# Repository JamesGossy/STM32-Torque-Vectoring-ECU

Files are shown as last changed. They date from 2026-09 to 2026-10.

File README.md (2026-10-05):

<div align="center">

# STM32 Torque Vectoring ECU

**Firmware for a four-motor torque vectoring and derating ECU on an STM32G474.**

The simulated car driving a full lap of the FSG 2024 track

*A lap of the Formula Student Germany 2024 track in the full-physics simulation this ECU
grew out of. Blue and yellow dots are cones, cyan is the racing line, the red box is the car.*

</div>

---

## What it does

The ECU sits on the car's CAN bus with four STM32 motor controllers (one per wheel,
from the STM32-Motor-Controller project). Every 10 ms it:

1. reads the driver's pedals and steering, its own IMU, and each controller's speed,
   temperature and bus voltage,
2. decides whether torque is allowed at all (startup, faults, plausibility checks),
3. works out how much torque the motors may give right now (derating),
4. splits the driver's torque request across the four wheels to help the car turn
   (torque vectoring),
5. sends each controller its current setpoint over CAN.

It can also run in **HIL mode**, where the Formula Student simulator stands in for
the car. The simulator sends steering, torque request, yaw rate and wheel speeds over
CAN, and reads back the torque the ECU commanded. The real motor controllers on the
bench take part exactly as they would on the car.

Battery management is out of scope for now: the bench runs from a lab power supply.

```mermaid
flowchart LR
    pedals["Pedals & steering"] -->|analog| ecu
    imu["IMU (LSM6DSV16X)"] -->|SPI| ecu
    ecu["Torque vectoring ECU<br/>STM32G474"]
    ecu <-->|"CAN 1 Mbit/s<br/>current setpoints / telemetry"| mc["Four motor controllers<br/>FL · FR · RL · RR"]
    sim["Formula Student sim<br/>(HIL mode)"] <-->|"CAN via CANable<br/>steering, torque request,<br/>yaw rate, wheel speeds"| ecu
    usb["PC console"] <-->|USB-C| ecu

    classDef controller fill:#eef2ff,stroke:#6366f1,color:#1e1b4b
    classDef drive fill:#ecfdf5,stroke:#059669,color:#064e3b
    classDef interface fill:#fff7ed,stroke:#ea580c,color:#7c2d12
    class ecu controller
    class mc,pedals,imu drive
    class sim,usb interface
```

## Repository layout

```
ECU_Hardware/            KiCad schematics and PCB, board requirements, sensor pinout
docs/                    pictures from the earlier full-physics simulation
ECU_Firmware/
  app/                   the application, no hardware access (runs on the board and the PC)
    app.c                100 Hz control step and the drive state machine
    torque_vectoring.c   the yaw-rate torque vectoring law
    derate.c             torque limits from temperature, speed and bus voltage
    driver_inputs.c      pedals and steering, with the Formula Student plausibility rules
    motors.c             the motor controller CAN protocol, client side
    hil.c                inputs from the HIL simulator
    imu.c, gps.c         LSM6DSV16X gyro/accel driver, NMEA reader
    console.c            USB text console
    config.h             every number: car, sensors, limits, derating thresholds
    can_protocol.h       every CAN message (shared with the simulator)
  hal/hal.h              what the app needs from a board
  hal/stm32g474/         register-level drivers: clocks, ADC+DMA, SPI, UART, FDCAN, USB
  sim/                   the board in memory, and ecu_sim for simulator runs
  tests/                 unit and whole-application tests
Makefile                 shortcuts for the CMake builds, tests and formatting
```

The application only ever talks to `hal.h`. On the board that is the STM32 drivers;
on a PC it is `sim/sim.c`. The same application code is what gets tested, what runs in
the simulator, and what runs on the car.

## Torque vectoring

The steering angle and speed give the yaw rate the driver is asking for (a bicycle
model). The gyro gives the yaw rate the car really has. The difference moves torque
from one side of the car to the other:

```
base            = request / 4, inside the derated limits
target yaw rate = speed * tan(steering * 0.23) / wheelbase
correction      = 4 Nm per rad/s * (target - measured), at most 4 Nm,
                  and never more than the room both sides have left
left wheels     = base - correction
right wheels    = base + correction
```

The total torque never changes, only how it is shared. It works under regen too. The
law and gains are the same as the simulator's own software torque vectoring, so an HIL
lap can be compared directly with a pure simulation lap.

This is what it looks like on a car. Both pictures come from the full-physics simulation
this project started as, which used a grip-aware PID version of the same idea. At the
hairpin the outer wheels drive and the inner wheels regen, which swings the car round:

<div align="center">
The car at the hairpin with the four wheel-torque bars showing the left/right split
</div>

Through a corner the four wheel torques start together, then fan apart as each wheel is
given its own share:

<div align="center">
The four wheel torques fanning apart through a corner
</div>

## Derating

One factor covers the whole car, so derating never adds a yaw moment of its own.

| Input | Starts at | Zero torque at | Limits |
| --- | --- | --- | --- |
| Controller FET temperature | 80 C | 95 C (controllers trip at 100 C) | drive and regen |
| ECU board temperature | 70 C | 85 C | drive and regen |
| Motor speed (from the controllers) | 70 % of 10k rpm | 10k rpm | drive |
| Bus voltage, sagging | 14 V | 10 V (controllers trip at 8 V) | drive |
| Bus voltage, rising | 50 V | 56 V (controllers trip at 60 V) | regen |
| Car speed | 2 m/s | standstill | regen |

Regen fades out as the car stops, because at standstill a regen request would drive the
motors backwards. The rising-bus limit matters on the bench: a lab supply cannot absorb regen, so the bus
voltage climbs. The speed limit uses the speed the controller measures, because that
protects the real motor. An unloaded bench motor settles just under its limit instead of
running away. All thresholds are in `config.h`.

## When torque is allowed

| State | Meaning |
| --- | --- |
| `STARTUP` | first second: the gyro bias is measured, so the car must be still |
| `STANDBY` | ready, no torque. Controllers are kept idle |
| `DRIVE` | torque is sent every 10 ms |
| `FAULT` | latched after a hard stop while driving. No torque until `clear` on the console or a power cycle |

To arm, press the brake with the throttle released and hold it for 1 s in standby (a
stand-in until the car has a ready-to-drive button). After any disarm the brake has to be
lifted and pressed again. In HIL mode the simulator arms it instead, with a fresh drive
request. Arming needs every
controller online and healthy, main power present (so the pedal sensors are powered), a
working IMU and a healthy CAN bus.

Any of those failing while driving latches `FAULT` and keeps the cause in the status frame, so a flickering fault cannot re-arm the car. Two pedal problems
only zero the torque while they last, as the Formula Student rules ask:

- **Throttle sensor disagreement:** the two throttle sensors differ by more than 10 %
  for over 100 ms.
- **Brake with throttle:** the brake and more than 25 % throttle are pressed together.
  Torque stays at zero until the throttle drops below 5 %.

Torque only goes out once all four controllers are running, so one side can never drive
alone. On disarm the ECU sends zero current and an idle request to every controller at
once, and keeps sending zero current while disarmed. The controllers also stop by
themselves 250 ms after their setpoints stop, so a crashed or unplugged ECU is safe. The
watchdog resets the ECU after 100 ms.

## Steering wheel panel

The panel is a CAN node (17) that sends three dial values: torque vectoring strength,
drive power and regen. They scale the yaw correction and the drive and regen torque
limits, on top of derating. Without a panel everything stays at 100 %. If the panel goes
quiet the last values are kept, so a lost cable never raises a limit. The panel lights
its LEDs from the ECU's `STATUS` frame (state and inhibit bits). The console `status`
line shows the dial values.

## CAN bus

Classic CAN at 1 Mbit/s, 11-bit ids of the form `(node << 5) | message`, the scheme the
motor controllers already use. Floats are little endian. The full list is in
[`can_protocol.h`](ECU_Firmware/app/can_protocol.h).

| Node | Who | Messages |
| --- | --- | --- |
| 1 to 4 | motor controllers FL, FR, RL, RR | ECU sends `SET_STATE`, `SET_IQ`. They send heartbeat, iq and speed, bus volts and temperature |
| 16 | this ECU | `STATUS` (state, inhibit bits, derating) and `YAW` (target and measured) every 10 ms |
| 17 | steering wheel panel | `DIALS`: torque vectoring %, drive power %, regen % (0 to 100) |
| 16 | HIL simulator | `DRIVER`, `WHEELS_F`, `WHEELS_R`, then `CONTROL` last each tick |

Wheel torque is sent as controller current: 1.47 Nm per amp maps the car motor's 29.4 Nm
onto the controller's 20 A limit. The left motors are mounted mirrored, so their current
has the opposite sign. Set each controller's node id from its own console with `node <id>`.

## Build, flash and test

Needs CMake and Ninja, plus `arm-none-eabi-gcc` for the board (STM32CubeCLT has all
three) and a host C compiler for the tests.

```
make firmware     # ECU_Firmware/build/tv_ecu.elf, .hex and .bin
make flash        # over SWD with an ST-LINK and STM32CubeProgrammer
make test         # unit tests and whole-application tests on the PC
make test MC_DIR=../STM32-Motor-Controller/controller_firmware   # also the controller interop test
```

The interop test builds the real motor controller firmware for the PC and runs it
against this ECU. It checks that the ECU arms the controller, that the controller follows
the commanded current, that speed derating holds a free motor near its limit, and that
the controller stops when drive is switched off and when the ECU goes away.

## USB console

Plug in USB-C and open the virtual COM port with any terminal.

| Command | Does |
| --- | --- |
| `status` | state, inputs, torques, derating and any inhibit reasons |
| `stream on` / `stream off` | the status line every 100 ms |
| `motors` | one line per motor controller |
| `gps` | the latest GPS fix |
| `off` | stop sending torque |
| `clear` | ask every controller to clear its faults |
| `estop` | broadcast the controller e-stop |

## HIL testing with the Formula Student simulator

```
PC: Formula Student sim --TCP-- can_bridge.py --USB-- CANable 2.0 --CAN-- ECU board
                                                                    \-- motor controllers
```

1. Wire the CANable, the ECU and the motor controllers on one bus, terminated at both
   ends (the ECU has fixed split termination). Power the ECU and controllers from the
   bench supply.
2. Calibrate each motor controller and give it its node id (1 FL, 2 FR, 3 RL, 4 RR).
   Controllers you do not have are played by the simulator.
3. Start the bridge, with the CANable's COM port:
   `python tools/can_bridge.py --channel COM5`
4. Run the simulator with `HIL=1`, for example `HIL=1 python visualiser.py` or
   `HIL=1 make eval` in the simulator repo.

The simulator listens for 0.3 s to find which controllers are real, waits for the ECU to
reach standby, arms it, then drives. It drives the car model with the current the ECU
commanded; set `HIL_TORQUE=measured` to use the current the real controllers report
instead (useful with loaded motors). `HIL_FET_TEMP` and `HIL_BUS_V` change what the
simulated controllers report, to try derating.

Without any hardware, `ecu_sim` (built by `make sim`) plays the ECU on the PC and the
simulator talks to it in lock-step. The simulator's `make test-hil` runs its whole lap
matrix that way.

### Driverless mode

Set `HIL_AUTONOMY=ecu` in the simulator and the ECU does the driving. The simulator sends
the nearest 16 cones (range in cm, bearing in mrad, colour) as `HIL_MSG_CONE` frames, one
per cone, ahead of each `CONTROL` frame. Every 10 ms the ECU turns them into a centre line
(`app/planner.c`), steers with pure pursuit and sets the total torque request with a
proportional speed controller (`app/autonomy.c`), then sends the result back in
`ECU_MSG_COMMAND`. Torque vectoring, derating and the state machine work as before.

| Runs on the ECU | Runs on the PC |
| --- | --- |
| Cone gating and midpoints, pure pursuit, speed control, steering rate limit | Vehicle model, cone sensor, EKF-SLAM (display only) |

If complete cone scans stop arriving for 50 ms the ECU latches FAULT (`cones-lost`), like
any other hard stop. The planner and controller are a port of the simulator's own, with
fixed constants in `config.h`, so laps match the simulator's software autopilot only at
its default tunables. `make test-hil` in the simulator repo checks this.

**On the bench:** the motors are unloaded, so any torque spins them up until speed
derating holds them just under 10k rpm. Keep them guarded and clamped down.

## Not done yet

- Battery and BMS messages, and derating from state of charge.
- Pedal and steering calibration stored in flash (it is in `config.h` for now).
- A ready-to-drive button input.
- GPS is read and shown on the console, but not used by the controller.
- The IMU interrupt pin and the GPS PPS pin are wired but not used.

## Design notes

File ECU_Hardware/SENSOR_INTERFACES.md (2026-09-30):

# GPS, IMU and ambient temperature interfaces

Implemented in `ECU_Hardware/schematics/` and connected through `stm32_ecu.kicad_sch` to U11, STM32G474CEUx. PCB routing and firmware implementation are separate work.

## STM32 pin allocation

Signal names use the MCU perspective.

| Signal | MCU pin | Package pad | Configuration | Sensor connection |
|---|---|---:|---|---|
| GPS_TX | PA9 | 31 | USART1_TX, AF7 | U1 RXD, pad 3 |
| GPS_RX | PA10 | 32 | USART1_RX, AF7 | U1 TXD, pad 2 |
| GPS_PPS | PA8 | 30 | TIM1_CH1 input capture, AF6; alternatively EXTI8 | U1 1PPS, pad 4 |
| IMU_SCK | PA5 | 13 | SPI1_SCK, AF5 | U3 SCL/SPC, pad 13 |
| IMU_MISO | PA6 | 14 | SPI1_MISO, AF5 | U3 SDO, pad 1 |
| IMU_MOSI | PA7 | 15 | SPI1_MOSI, AF5 | U3 SDA/SDI, pad 14 |
| IMU_CS_N | PA4 | 12 | GPIO output, initially high | U3 CS, pad 12 |
| IMU_INT | PC4 | 16 | EXTI4 input | U3 INT1, pad 4 |
| TEMP_SENSE | PA0 | 8 | ADC1_IN1, analog, no pulls | R5/TH1/C11 junction |

Existing CAN, USB and SWD pin assignments are preserved. Pedal, steering and VIN input interfaces remain reserved and unfinished.

## GPS

U1 remains the selected ATGM336H-5N31. It uses board 3.3 V with 10 µF bulk and 100 nF bypass capacitors. VBAT also uses board 3.3 V with a separate 100 nF bypass: there is no backup battery, so backup retention is lost when board power is removed.

J3 is a U.FL connector for an **external 3.3 V active GNSS antenna**. L4 is a 47 nH RF choke feeding the antenna from the module's VCC_RF output, following its active antenna reference circuit. Select an antenna with compatible supply/current and the module's specified 15–30 dB gain range. The module's antenna short-circuit limit is approximately 50 mA. Budget up to 100 mA module peak current plus antenna current when checking the complete 3.3 V regulator load.

ON/OFF and nRESET are deliberately left open as in the reference circuit; reserved and unused interfaces have no-connect markers. UART configuration and PPS capture still need firmware. Route the antenna feed as a short 50 Ω line over continuous ground, away from the buck switch node and fast digital traces. Place bypass capacitors at their respective module pins and check supply ripple against the 50 mVpp recommendation. The antenna is part of the GNSS subsystem; external pedal/steering supply policy is unchanged.

## IMU

U3 remains LSM6DSV16XTR, configured for four-wire SPI in connection mode 1. Both supply pins use 3.3 V with separate 100 nF bypass capacitors and 1 µF local bulk. A 10 kΩ CS pull-up keeps the device deselected while the MCU resets.

INT1 connects to PC4. INT2 and auxiliary pins 10/11 are unused. Pins 2/3 are grounded as specified when the sensor hub, analog hub and Qvar functions are disabled. Their project symbol electrical types are input to represent this mode; do not enable the sensor-hub output functions with this wiring. Other imported pin types were corrected from unspecified to their documented functions in both the project library and schematic cache.

Firmware must initialize the sensor, configure SPI, choose ranges and sample rates, route data-ready/FIFO events to INT1, and calibrate the installed axes. Place the IMU rigidly and document orientation on the PCB.

## Temperature

TH1 is Murata NCU18XH103F60RB: 10 kΩ at 25 °C, ±1%, B25/50 = 3380 K ±1%. R5 changes from 4.7 kΩ to 39 kΩ ±1% to reduce excitation current and self-heating. C11 is 100 nF to ground.

At 25 °C and a 3.3 V supply, the divider produces about 0.673 V, draws 67 µA, and dissipates 0.045 mW in the NTC. The filter corner is approximately 200 Hz at that temperature. Hotter temperatures produce lower ADC voltages.

Use a long ADC acquisition time, such as 247.5 ADC clock cycles, and average samples. Account for the actual ADC reference and divider supply. Calculate `Rntc = 39000 × Vout / (V3V3 − Vout)` and use Murata's resistance/temperature table; the beta equation is an approximation. Detect near-ground and near-supply readings as possible short/open faults. Place TH1 at a ventilated board edge away from heat sources. Its reading represents local board/enclosure temperature; layout determines how closely that follows ambient air.

## Libraries and verification

Resistors and capacitors use the installed PCM_JLCPCB symbols and footprints with their existing manufacturer/LCSC fields. The installed catalog lacks the selected NTC and 47 nH RF choke, so `libraries/PCM_JLCPCB-Project.kicad_sym` is an explicitly documented **project extension**, registered in `sym-lib-table`:

| Part | Manufacturer | LCSC | PCM footprint |
|---|---|---|---|
| NCU18XH103F60RB | Murata | C440252 | R_0603 |
| LQW15AN47NG00D | Murata | C22334 | L_0402 |

KiCad 10 netlist checks confirm all nine signals, supplies, grounds, pull-up, antenna bias and thermistor connectivity. Existing connections outside the replaced sensor circuits are preserved. References are unique, and the selected footprints exist with the connected pad numbers. The rendered hierarchy and five affected pages were inspected.

ERC findings reduced from 188 to 89. There are no ERC findings on the GPS, IMU or ambient temperature pages. The remaining findings concern existing circuitry, missing libraries/footprints elsewhere and unfinished reserved interfaces; this is not a whole-board manufacturing sign-off.

## Datasheet references

- [STM32G474 datasheet](https://www.st.com/resource/en/datasheet/stm32g474ce.pdf), pin definitions and alternate functions.
- [LSM6DSV16X datasheet](https://www.st.com/resource/en/datasheet/lsm6dsv16x.pdf), section 7 and Table 23.
- [ATGM336H-5N manufacturer user manual](https://datasheet4u.com/pdf/1260662/ATGM336H-5N.pdf), sections 2.4–2.8; manufacturer document hosted by a distributor/archive.
- [Murata NCU18 specifications](https://www.murata.com.cn/products/productdata/8828036775966/SPEC-NCU18.pdf?1728271827000=).
- [Murata LQW15AN47NG00D](https://www.murata.com/en-us/products/productdetail?partno=LQW15AN47NG00D).

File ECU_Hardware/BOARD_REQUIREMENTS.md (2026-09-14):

# STM32 Torque Vectoring ECU — Board Requirements

Status: Design draft | Updated: 2026-09-13

This STM32 board runs torque vectoring and derating algorithms. Four brushless motor controllers and a BMS communicate with it over CAN. The board commands torque; it does not directly drive motors. This document records requirements, not verification of the existing schematic.

**Confirmed** items reflect agreed scope. **Proposed** items are recommendations. **TBD** items must be resolved during design.

## 1. Confirmed scope

| Block | Requirement |
| --- | --- |
| Main input | 12–60 V DC through a keyed XT60 connector. |
| Buck regulator | Convert the main input to 5 V. |
| USB-C | Supply board power for testing and provide a diagnostic/debug interface. |
| Power ORing | Combine buck and USB 5 V through ideal-diode circuitry, preventing backfeeding into either source. |
| Logic supply | Generate 3.3 V from combined 5 V using an LDO. |
| External sensors | Must not receive power from USB-C. |
| MCU | STM32 with sufficient computation, memory and peripherals, including CAN FD capability. Part TBD. |
| IMU | Onboard inertial sensing for the control algorithm. |
| GPS | GPS/GNSS data; receiver and antenna arrangement TBD. |
| Driver inputs | Steering angle, accelerator pedal position and brake pedal position. Sensors/interfaces selected during board design. |
| CAN | One CAN FD-capable bus with two connectors for daisy chaining. |
| Temperature | Ambient temperature sensing. |
| Indicators | Indicator LEDs; functions/count TBD. |
| Programming | SWD header for an external ST-LINK. |
| Protection/monitoring | TVS input protection and input rail voltage monitoring. |
| Environment | Approximately 30 °C ambient; full operating limits TBD. |

## 2. CAN interfaces

### Four motor controllers

Receive from each controller:

- Motor/wheel speed information, with units and motor-to-wheel conversion defined.
- Motor and inverter temperatures.
- Echoed torque and speed setpoints.
- D-axis and q-axis currents (`Id` and `Iq`).

Send individual torque commands over CAN. An echoed torque setpoint is command feedback, not an independent measurement of actual torque.

Proposed: receive readiness, status and faults where supported by the controller protocol.

### BMS

Receive all BMS information needed for derating, including state of charge and temperatures. Finalise the complete signal list during protocol design, including applicable pack voltage/current, charge/discharge limits and fault/status messages. No dedicated motor/battery temperature inputs are currently required on this board.

### Hardware and protocol

- Use an appropriate STM32 FDCAN peripheral and CAN FD-rated transceiver.
- Wire both connectors to the same CAN_H/CAN_L network; these are not independent channels.
- Proposed: selectable termination, enabled only when the ECU is at a physical bus end.
- Define connector pinout, reference ground, shielding, protection and any isolation requirement.
- Define arbitration/data rates, identifiers, payloads, units, scaling, update rates, timeouts and bus-load budget.
- Confirm that all attached devices support the intended network mode. ECU CAN FD capability alone does not establish whole-network FD compatibility.

## 3. Power architecture

```text
XT60 12–60 V -> protection/filtering -> 5 V buck -> ideal diode --+
                                             |                |
                                             +-> external     +-> board 5 V
                                                 sensor rail  |      |
USB-C 5 V ------------------------------------> ideal diode --+      +-> LDO -> 3.3 V
```

The external sensor supply branch shall be fed before ORing, from main-input power only. Provide any additional regulation required by the selected sensors. External sensors shall not be connected directly to the combined board rail.

- Prevent reverse current into USB and the buck output.
- Prevent phantom powering of external sensors through signal pins during USB-only operation; check powered/unpowered interfaces in both directions.
- Define main-only, USB-only and simultaneous-source operation, including source insertion/removal.
- Proposed: inhibit torque commands in USB-only test mode and identify unavailable external sensors in diagnostics.
- Calculate board and external-sensor current budgets before selecting regulators.
- Implement USB-C sink CC configuration and respect the source's advertised current capability. USB PD is not a confirmed requirement.
- Check LDO heat dissipation: approximately `(5 V - 3.3 V) × load current`, plus quiescent losses.

### Protection decisions

| Item | Requirement/status |
| --- | --- |
| TVS | Confirmed. Select standoff, clamping voltage and pulse capability against the actual supply envelope and protected component ratings. |
| Input monitoring | Confirmed. Use a scaled, filtered and protected ADC input; account for an unpowered MCU. Monitoring does not replace hardware protection. |
| OCP | Proposed: a board-input fuse or documented upstream fused feed sized for ECU wiring/input circuitry, plus buck current-limit/short-circuit protection. A separate electronic OCP IC is not automatically required. |
| Active OVP | TBD; not mandatory at this stage. Decide from supply fault/transient limits and component ratings. Do not assume a TVS can absorb sustained overvoltage indefinitely. |
| Reverse polarity | Dedicated protection omitted from current scope, assuming a correctly wired keyed XT60 harness. Keying prevents reversed mating but not reversed harness wiring; verify polarity during assembly. |
| External sensor faults | Proposed: current limiting/fault containment appropriate to the selected sensor loads. |

Clarify whether 60 V includes the maximum normal charging/regeneration voltage. Check operating and absolute maximum ratings against the input/transient envelope and TVS clamp voltage; do not select components solely from a nominal “60 V” rating.

## 4. Sensor requirements

### Steering and pedals — TBD during board design

For each sensor, determine:

- Supply voltage/current and connector pinout.
- Interface type: analogue, PWM, digital bus or other.
- Signal range, accuracy, bandwidth and sample rate.
- Channel count, including redundant accelerator channels if the chosen pedal uses them.
- Filtering, electrical protection and open/short-circuit detection.
- Calibration procedure and persistent storage.

Do not freeze connector pin counts or ADC allocation before selecting these interfaces.

### IMU, GPS and ambient temperature

- Select IMU axes, ranges, sample rates, interface and interrupts to suit the algorithm; document orientation and calibration.
- Define GPS update rate, interface, antenna placement/connector, any active-antenna supply and whether PPS timing is needed.
- Define invalid/stale sensor handling and required accuracy.
- Place the ambient sensor away from regulator heating where practical. Decide whether the measurement represents enclosure air or PCB temperature.

## 5. MCU, programming and diagnostics

- Finalise STM32 computation, memory and peripheral/pin allocation against algorithm timing and interfaces.
- Implement device-specific decoupling, analogue supply/reference, clock, reset and boot requirements.
- SWD header: SWDIO, SWCLK, NRST, ground and target-voltage reference; SWO optional.
- Define USB diagnostics and any firmware-update support. External ST-LINK uses the SWD header; onboard ST-LINK is not currently required. Native USB diagnostics alone do not provide breakpoint debugging.
- Proposed LEDs: power, firmware heartbeat, CAN activity and fault.
- Proposed test points: input, buck 5 V, USB 5 V, combined 5 V, 3.3 V, ground and reset.
- Provide persistent calibration/configuration storage. External memory or bulk logging is optional unless internal resources are insufficient.

## 6. Control and fault behaviour — proposed

- Define control-loop period, maximum latency and input freshness limits.
- Inhibit torque at startup until required inputs and controller/BMS status are valid.
- Define responses to implausible driver inputs, stale feedback, BMS/controller faults and CAN bus-off.
- Use watchdog and brownout/reset handling with defined recovery behaviour.
- Require receiving motor controllers to time out stale torque commands. Sending a final zero-torque command cannot be relied on after ECU power or communication loss.
- Define fault-specific torque responses, timeouts and recovery conditions; values TBD.
- Decide whether the vehicle architecture needs an independent hardware torque-inhibit/interlock interface.
- Report diagnostic faults and retain useful fault information where practical.

## 7. Thermal and mechanical requirements

The intended ambient condition is approximately 30 °C. Verify buck/LDO self-heating at maximum load and across the input range; component junction temperature can be substantially above ambient.

Board dimensions, mounting, enclosure, connector access, harness strain relief and environmental exposure limits remain TBD. Preserve practical SWD and test-point access.

## 8. Verification checklist

- Verify regulated rails across 12–60 V input and the agreed load range.
- Verify both-source, USB-only and main-only operation, source transitions and reverse-current blocking.
- Verify external sensors remain unpowered on USB-only supply, including signal-pin backfeeding checks.
- Measure regulator temperature rise at approximately 30 °C ambient under worst-case load.
- Check input-voltage measurement accuracy and protection ratings against the agreed input envelope.
- Verify SWD programming/debugging and USB diagnostics.
- Exercise the intended CAN mode with all four controllers and the BMS; check termination, timing and bus load.
- Validate selected driver sensors, calibration and fault detection.
- Validate IMU/GPS data, orientation, timing and temperature sensing.
- Verify startup inhibition, watchdog recovery, stale-data handling and receiving-controller command timeouts.

## 9. Remaining decisions

1. STM32 part, pin allocation and timing/resource budgets.
2. Pedal/steering sensor selection and interfaces.
3. Supply/transient envelope, fuse arrangement and need for active OVP.
4. Regulators, current budgets and external sensor supply implementation.
5. CAN protocol, rates, connectors, protection and isolation.
6. IMU/GPS parts and measurement requirements.
7. Control/fault timing, derating thresholds and hardware interlock decision.
8. USB functions, LEDs, mechanical dimensions and environmental limits.

## References

- [TI power protection overview](https://www.ti.com/product-category/power-management/power-protection-switches-controllers/overview.html): protection options; not a requirement to use a dedicated protection IC.
- [TI input protection and buck reference design](https://www.ti.com/lit/pdf/tiduee8): example of coordinated protection; component choices require evaluation for this board's input envelope.
- [ST STM32 hardware development guidance](https://www.st.com/resource/en/application_note/an6011-getting-started-with-stm32u3-mcu-hardware-development-stmicroelectronics.pdf): example MCU/debug support requirements; use the matching guide for the selected STM32.

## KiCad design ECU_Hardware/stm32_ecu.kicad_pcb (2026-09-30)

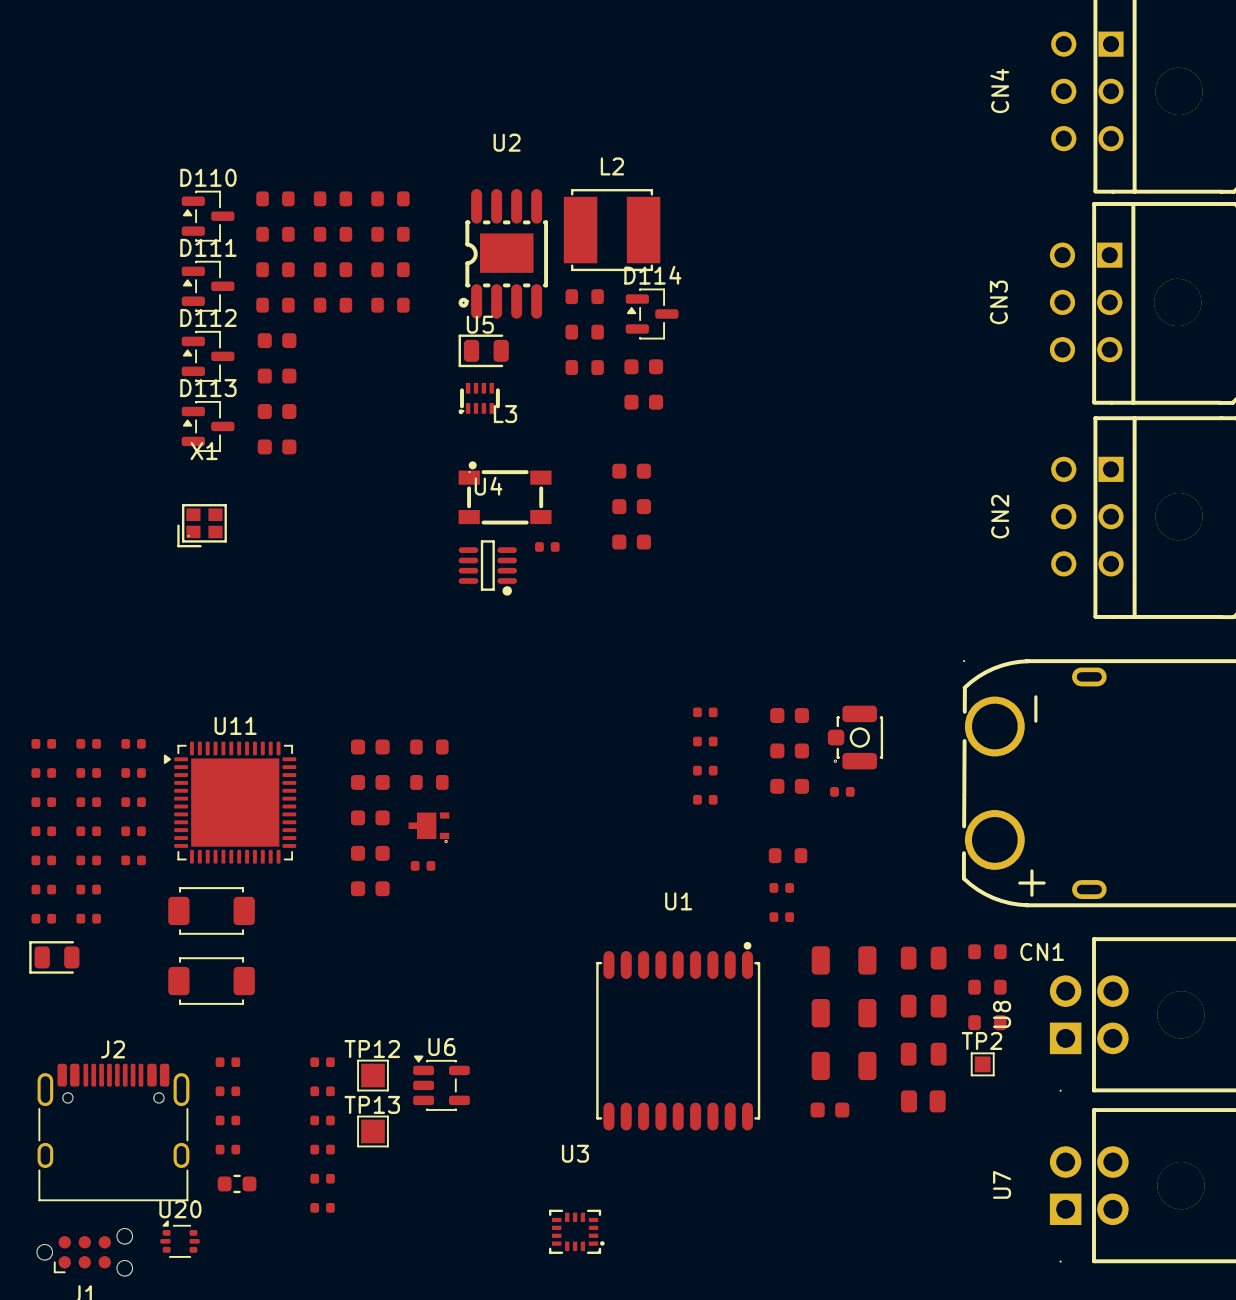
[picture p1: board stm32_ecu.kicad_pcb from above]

Board: 2 copper layers, 118 parts (0 on the bottom side), 69 nets, no tracks yet.

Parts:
C1: 100nF; C_0805
C2, C7, C37, C42, C45, C50, C93: 1uF; C_0402
C5, C92, C101, C102, C120, C121, C122, C124: 100nF; C_0603
C6, C26, C32, C44: 100pF; C_0603
C8, C9, C11, C12, C20, C21, C22, C23, C28, C38, C39, C52: 100nF; C_0402
C10, C43: 15pF; C_0402
C15: 4.7uF; C_0402
C30, C34, C35: 4.7uF; C_1206
C54, C55: 2.2uF; C_0402
C58, C79: 22uF; C_0805
C100: 10uF; C_0603
C110, C111, C112, C113: 10nF; C_0603
C123: 22uF; C_0603
CN1: XT60PW-M; CONN-TH_XT60PW-M
CN2, CN3, CN4: XDWF-C3030WR-2*3P; CONN-TH_XDWF-C3030WR-2X3P
D9: ESDCAN03-2BWY; DFN2020-3_L2.0-W2.0-P1.30-BR-1
D14, D15: White; D_0805
D110, D111, D112, D113, D114: BAT54S; SOT-23
FB1, FB2: 600Ω; R_0402
FB3: 120Ω @100MHz; FB_0603
J1: TC2030-NL; Tag-Connect_TC2030-IDC-NL_2x03_P1.27mm_Vertical
J2: USB_C_Receptacle_USB2.0_16P; USB_C_Receptacle_HRO_TYPE-C-31-M-12
J3: U.FL; IPEX-SMD_BWIPX-1-001E
L2: SWPA5040S150MT; IND-SMD_L5.0-W5.0
L3: ACT45B-101-2P-TL003; FILTER-SMD_4P-L4.5-W3.2-TL_ACT45B
L4: 47nH; L_0402
R1: 220kΩ; R_0603
R2, R5, R16: 10kΩ; R_0402
R3: 39kΩ; R_0402
R4, R26: 10kΩ; R_0603
R8: 200Ω; R_0402
R18, R19: 22Ω; R_0402
R23, R51: 100kΩ; R_0402
R25: 40.2kΩ; R_0603
R27: 64.9kΩ; R_0603
R29, R30: 5.1kΩ; R_0402
R38: 100kΩ; R_0805
R64, R65: 60.4Ω; R_0603
R110, R113, R116, R119: 33kΩ; R_0603
R111, R114, R117, R120: 47kΩ; R_0603
R112, R115, R118, R121, R130: 1kΩ; R_0603
S1, S2: Tactile Button, 160gf; SW_TS-1088-AR02016
TH1: 10k NTC; R_0603
TP2: 5V; TestPoint_Pad_1.0x1.0mm
TP12, TP13: TestPoint; TestPoint_Pad_1.5x1.5mm
U1: ATGM336H-5N31; GPSM-SMD_ATGM336H-TR
U2: LMR38020SQDDARQ1; SOIC-8_L4.9-W3.9-P1.27-LS6.0-BL-EP3.4
U3: LSM6DSV16XTR; LGA-14_L3.0-W2.5-P0.50-BR
U4: TCAN337GDCNR; SOT-23-8_L3.0-W1.7-P0.65-LS2.8-BR
U5: LM66200DRLR; SOT-583-8_L2.1-W1.2-P0.50-LS1.6-BL
U6: AP2112K-3.3; SOT-23-5
U7, U8: XD-43045-2*2AW; CONN-TH_4P-P3.00_XUNDA_XD-43045-2_2AW
U11: STM32G474CEUx; QFN-48-1EP_7x7mm_P0.5mm_EP5.6x5.6mm
U20: USBLC6-2P6; SOT-666
X1: XC7EL89COO-114YLC-16M; CRYSTAL-SMD_4P-L2.0-W1.6-BL

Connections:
5V_OR: C45.1, TP12.1 (1_1), U5.2 (VOUT), U5.7 (VOUT), U6.1 (VIN), U6.3 (EN)
+3V3: C7.1, C9.1, C11.1, C12.1, C15.1, C20.1, C21.1, C22.1, C23.1, C93.1, C100.1, C101.1, C102.1, D110.2 (K), D111.2 (K), D112.2 (K), D113.2 (K), D114.2 (K), FB1.1, J1.1 (VCC), R2.1, R3.1, R5.2, R23.1, R130.1, S2.1 (A), TP13.1 (1_1), U1.6 (VBAT), U1.8 (VCC), U3.5 (Vdd_IO), U3.8 (Vdd), U4.3 (Vcc), U6.5 (VOUT), U11.1 (VBAT), U11.23 (VDD), U11.35 (VDD), U11.48 (VDD)
+5V_BUCK: C37.1, C58.1, C79.1, C123.1, L2.2, R25.1, R38.1, TP2.1 (1_1), U5.6 (VIN2)
+5V_USB: C42.1, C55.1, FB3.2, U5.3 (VIN1)
/APPS_1: C110.1, D110.3 (COM), R112.2, U11.9 (PA1)
/APPS_1_RAW: CN2.3, R110.1
/APPS_2: C111.1, D111.3 (COM), R115.2, U11.10 (PA2)
/APPS_2_RAW: CN2.6, R113.1
/BPPS: C112.1, D112.3 (COM), R118.2, U11.11 (PA3)
/BPPS_RAW: CN3.3, R116.1
/CAN_FAULT: R5.1, U4.5 (FAULT), U11.42 (PB4)
/CAN_RX: U4.4 (RXD), U11.43 (PB5)
/CAN_TX: U4.1 (TXD), U11.44 (PB6)
/CAN_UNFIL_N: C44.1, L3.3, R65.1, U7.2, U8.2
/CAN_UNFIL_P: C32.2, L3.4, R64.1, U7.1, U8.1
/Connectors/APPS_5V: C120.1, CN2.1, CN2.4
/Connectors/BPPS_5V: C121.1, CN3.1, CN3.4
/Connectors/CC1: J2.A5 (CC1), R30.1
/Connectors/CC2: J2.B5 (CC2), R29.1
/Connectors/D+: J2.A6 (D+), J2.B6 (D+), U20.1 (I/O2)
/Connectors/D-: J2.A7 (D-), J2.B7 (D-), U20.6 (I/O1)
/Connectors/STEERING_5V: C122.1, CN4.1, CN4.4
/Connectors/USB_VBUS: C54.1, FB3.1, J2.A4 (VBUS), J2.A9 (VBUS), J2.B4 (VBUS), J2.B9 (VBUS), U20.5 (VBUS)
/GPS/GPS_ANT_BIAS: L4.2, U1.14 (VCC_RF)
/GPS_PPS: U1.4 (1PPS), U11.30 (PA8)
/GPS_RX: U1.2 (TXD), U11.32 (PA10)
/GPS_TX: U1.3 (RXD), U11.31 (PA9)
/IMU_CS_N: R2.2, U3.12 (CS), U11.12 (PA4)
/IMU_INT: U3.4 (INT1), U11.16 (PC4)
/IMU_MISO: U3.1 (SDO/SA0), U11.14 (PA6)
/IMU_MOSI: U3.14 (SDA), U11.15 (PA7)
/IMU_SCK: U3.13 (SCL), U11.13 (PA5)
/MCU/BOOT0: R16.1, S2.2 (B), U11.46 (PB8)
/MCU/HEARTBEAT: R8.1, U11.47 (PB9)
/MCU/HSE_IN: C43.1, U11.5 (PF0), X1.3
/MCU/HSE_OUT: C10.1, U11.6 (PF1), X1.1
/Power Regulation/ON: R51.1, U5.4 (~ON)
/Power Regulation/PWR_LED_A: D15.2, R130.2
/Power Regulation/ST: R23.2, U5.8 (ST)
/STEERING: C113.1, D113.3 (COM), R121.2, U11.17 (PB0)
/STEERING_RAW: CN4.3, R119.1
/SWCLK: J1.4 (SWCLK), R19.2
/SWDIO: J1.2 (SWDIO), R18.2
/SWO: J1.6 (SWO), U11.41 (PB3)
/TEMP_SENSE: C8.1, R3.2, TH1.1, U11.8 (PA0)
/USB_D+: U11.34 (PA12), U20.3 (I/O2)
/USB_D-: U11.33 (PA11), U20.4 (I/O1)
/VIN_12_60V: C1.1, C30.1, C34.1, C35.1, CN1.2 (+), R1.1, U2.2 (EN), U2.3 (VIN)
/VIN_SENSE: C124.1, D114.3 (COM), R1.2, R4.1, U11.18 (PB1)
/nRST: C52.1, J1.3 (~RESET), S1.2 (B), U11.7 (PG10)
GND: C1.2, C2.2, C5.1, C6.1, C7.2, C8.2, C9.2, C10.2, C11.2, C12.2, C15.2, C20.2, C21.2, C22.2, C23.2, C26.2, C28.2, C30.2, C32.1, C34.2, C35.2, C37.2, C38.2, C39.2, C42.2, C43.2, C44.2, C45.2, C50.2, C52.2, C54.2, C55.2, C58.2, C79.2, C93.2, C100.2, C101.2, C102.2, C110.2, C111.2, C112.2, C113.2, C120.2, C121.2, C122.2, C123.2, C124.2, CN1.1 (-), CN1.3, CN1.4, CN2.2, CN2.5, CN3.2, CN3.5, CN4.2, CN4.5, D9.3 (K), D14.1, D15.1, D110.1 (A), D111.1 (A), D112.1 (A), D113.1 (A), D114.1 (A), J1.5 (GND), J2.A1 (GND), J2.A12 (GND), J2.B1 (GND), J2.B12 (GND), J2.SH (SHIELD), J3.2 (Ext), R4.2, R16.2, R26.2, R27.2, R29.2, R30.2, R51.2, R111.2, R114.2, R117.2, R120.2, S1.1 (A), TH1.2, U1.1 (GND), U1.10 (GND), U1.12 (GND), U2.1 (GND), U2.9 (EP), U3.2 (SDx/AH1/Qvar1), U3.3 (SCx/AH2/Qvar2), U3.6 (GND), U3.7 (GND), U4.2 (GND), U4.8 (S), U5.1 (GND), U5.5 (GND), U6.2 (GND), U7.3, U8.3, U11.49 (VSS), U20.2 (GND), X1.2 (GND), X1.4 (GND)
unnamed: C5.2, R64.2, R65.2
unnamed: D14.2, R8.2
unnamed: J3.1 (In), L4.1, U1.11 (RF_IN)
unnamed: R110.2, R111.1, R112.1
unnamed: R113.2, R114.1, R115.1
unnamed: R116.2, R117.1, R118.1
unnamed: R119.2, R120.1, R121.1
unnamed: C92.2, U2.7 (BOOT)
unnamed: R25.2, R26.1, U2.5 (FB)
unnamed: R38.2, U2.6 (PG)
unnamed: R27.1, U2.4 (RT/SYNC)
unnamed: C92.1, L2.1, U2.8 (SW)
unnamed: C6.2, D9.1 (A), L3.1, U4.7 (CANH)
unnamed: C26.1, D9.2 (A), L3.2, U4.6 (CANL)
unnamed: R18.1, U11.36 (PA13)
unnamed: R19.1, U11.37 (PA14)
VDDA: C2.1, C28.1, C38.1, FB1.2, FB2.2, U11.21 (VDDA)
VREF: C39.1, C50.1, FB2.1, U11.20 (VREF+)

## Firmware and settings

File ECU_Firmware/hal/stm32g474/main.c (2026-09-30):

/* Firmware entry point: bring up the board, then run the main loop forever. */
#include "app.h"
#include "hal.h"

int main(void)
{
    hal_init();
    app_init();
    hal_start();

    uint32_t last = hal_millis();
    for (;;) {
        app_poll();
        while (last != hal_millis()) { // catch up if the loop was slow, so no tick is lost
            last++;
            app_tick();
        }
    }
}

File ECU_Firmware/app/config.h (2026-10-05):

/* Every number the ECU firmware uses: the car, the sensors, the limits and the
   derating thresholds. Values marked "bench" suit the current bench setup with
   the STM32 motor controllers on a lab power supply. */
#ifndef CONFIG_H
#define CONFIG_H

/* ---- wheels ---- */

enum { WHEEL_FL, WHEEL_FR, WHEEL_RL, WHEEL_RR };

/* ---- timing ---- */

#define CONTROL_PERIOD_MS 10   // 100 Hz, same as the simulator
#define MOTOR_TIMEOUT_MS  50   // controllers send a heartbeat every 10 ms
#define MOTOR_START_MS    500  // time a controller gets to reach torque mode
#define MOTOR_RETRY_MS    100  // gap between repeated state requests
#define HIL_TIMEOUT_MS    50   // the simulator sends inputs every 10 ms
#define GYRO_CAL_MS       1000 // car must stay still while the gyro bias is measured
#define ARM_BRAKE_HOLD_MS 1000 // hold the brake this long to enable torque
#define APPS_DISAGREE_MS  100  // FS rules allow 100 ms of pedal sensor disagreement
#define CONSOLE_STREAM_MS 100

/* ---- vehicle ---- */

#define WHEELBASE_M          1.55f
#define WHEEL_RADIUS_M       0.254f
#define GEAR_RATIO           15.47f
#define STEERING_TO_WHEEL    0.23f   // road wheel angle per steering angle, the sim's ACK_NOMINAL
#define MOTOR_MAX_TORQUE_NM  29.4f   // at the motor shaft
#define MOTOR_MAX_SPEED_RADS 1047.2f // bench: 10k rpm, the controller's SPEED_MAX

/* ---- driver requests ---- */

#define DRIVE_REQUEST_MAX_NM (4.0f * MOTOR_MAX_TORQUE_NM) // full throttle
#define REGEN_REQUEST_MAX_NM (4.0f * MOTOR_MAX_TORQUE_NM) // full brake pedal

/* ---- torque vectoring ---- */

#define TV_KP_NM_PER_RADS    4.0f // extra torque per side for each rad/s of yaw error
#define TV_MAX_CORRECTION_NM 4.0f
#define TV_MIN_SPEED_MS      0.5f // below this the yaw target is meaningless

/* ---- derating ---- */

#define DERATE_FET_START_C  80.0f // controllers trip at 100 C
#define DERATE_FET_END_C    95.0f
#define DERATE_ECU_START_C  70.0f
#define DERATE_ECU_END_C    85.0f
#define DERATE_SPEED_START  0.70f // of max speed. A wide ramp keeps a free bench motor steady
#define DERATE_LOW_V_START  14.0f // bench: 24 V supply, controllers trip at 8 V
#define DERATE_LOW_V_END    10.0f
#define DERATE_HIGH_V_START 50.0f // bench: a lab supply cannot absorb regen, so the bus rises
#define DERATE_HIGH_V_END   56.0f // controllers trip at 60 V
#define REGEN_FULL_SPEED_MS 2.0f  // regen fades out below this, or it would drive backwards

/* ---- pedals and steering ---- */

// Sensor volts at the connector. The board divides them by 47k / (33k + 47k).
#define SENSOR_DIVIDER   (47.0f / 80.0f)
#define SENSOR_MIN_V     0.25f // below this the wire is open or shorted to ground
#define SENSOR_MAX_V     4.75f // above this it is shorted to the supply
#define APPS1_ZERO_V     0.5f
#define APPS1_FULL_V     4.5f
#define APPS2_ZERO_V     4.5f // second sensor runs the other way, so one fault cannot fool both
#define APPS2_FULL_V     0.5f
#define BPPS_ZERO_V      0.5f
#define BPPS_FULL_V      4.5f
#define STEER_CENTRE_V   2.5f
#define STEER_LEFT_V     4.5f // at full left lock
#define STEER_LOCK_RAD   2.4f // steering angle at full lock, the sim's g_MAX_STEER_RAD
#define PEDAL_DEADBAND   0.03f
#define APPS_DISAGREE    0.10f
#define BRAKE_ON         0.10f
#define BRAKE_APPS_CUT   0.25f // throttle above this with the brake on cuts torque
#define BRAKE_APPS_RESET 0.05f // until the throttle comes back below this

/* ---- board ---- */

#define ADC_VREF_V    3.3f
#define VIN_DIVIDER   21.0f // 200k over 10k
#define VIN_MIN_V     10.0f // below this the board runs from USB only
#define NTC_R_TOP_OHM 39000.0f
#define NTC_R25_OHM   10000.0f
#define NTC_BETA      3380.0f
#define IMU_YAW_SIGN  1.0f // flip if the board is mounted upside down

/* ---- driverless control ---- */

#define AUTO_CRUISE_SPEED_MS   6.0f  // speed on a straight, the sim's g_CRUISE_SPEED_MS
#define AUTO_LOOKAHEAD_M       3.0f  // how far ahead on the path the car aims
#define AUTO_SPEED_KP_NM       20.0f // total torque per m/s of speed error
#define AUTO_MAX_STEERING      2.4f  // steering units, the sim's g_MAX_STEER_RAD
#define AUTO_MAX_STEERING_RATE 8.0f  // steering units per second
#define AUTO_MIN_TARGET_M      0.2f  // a target closer than this is ignored
#define PLAN_MAX_GATE_M        10.0f // a blue and yellow cone further apart are not a gate
#define PLAN_EDGE_OFFSET_M     2.0f  // how far inside one edge to drive when only that edge is seen
#define PLAN_MIN_SEGMENT_M     0.2f
#define PLAN_MIN_POINT_GAP_M   0.3f
#define CONES_TIMEOUT_MS       50 // no cone frame for this long means perception is lost

/* ---- HIL ---- */

#define HIL_ALLOWED 1 // set to 0 for the car so nothing on the bus can replace the sensors

#endif

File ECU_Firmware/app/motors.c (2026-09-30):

/* Client side of the motor controller CAN protocol. Controllers drop to idle if
   setpoints stop for 250 ms, so the ECU resends every control period and never
   relies on a final zero command getting through. */
#include "motors.h"
#include "can_protocol.h"
#include "config.h"
#include "hal.h"
#include <string.h>

static Motor motors[4];
static int was_enabled;
static uint32_t enabled_ms;

void motors_init(void)
{
    memset(motors, 0, sizeof motors);
    was_enabled = 0;
}

static int wheel_of_node(uint32_t node)
{
    for (int wheel = 0; wheel < 4; wheel++) {
        if (MOTOR_NODE[wheel] == node) return wheel;
    }
    return -1;
}

int motors_handle_frame(uint32_t id, const uint8_t *data, uint8_t len, uint32_t now)
{
    int wheel = wheel_of_node(CAN_NODE(id));
    if (wheel < 0 || len < 8) return 0;
    Motor *m = &motors[wheel];

    switch (CAN_MSG(id)) {
    case MC_MSG_HEARTBEAT:
        m->state    = data[0];
        m->mode     = data[1];
        m->faults   = can_get_u16(data + 2);
        m->heard_ms = now;
        m->heard    = 1;
        return 1;
    case MC_MSG_IQ_SPEED:
        m->iq_a       = can_get_f32(data);
        m->speed_rads = can_get_f32(data + 4);
        return 1;
    case MC_MSG_BUS_TEMP:
        m->bus_v      = can_get_f32(data);
        m->fet_temp_c = can_get_i16(data + 4) / 10.0f;
        return 1;
    }
    return 0;
}

const Motor *motor_get(int wheel)
{
    return &motors[wheel];
}

int motor_online(int wheel, uint32_t now)
{
    return motors[wheel].heard && now - motors[wheel].heard_ms <= MOTOR_TIMEOUT_MS;
}

int motor_healthy(int wheel, uint32_t now)
{
    const Motor *m = &motors[wheel];
    int usable     = m->state == MC_STATE_IDLE || m->state == MC_STATE_RUN;
    return motor_online(wheel, now) && usable && m->faults == 0;
}

float motor_wheel_speed(int wheel)
{
    return motors[wheel].speed_rads * MOTOR_DIRECTION[wheel] / GEAR_RATIO;
}

static void send_state(int wheel, uint8_t run, uint32_t now)
{
    hal_can_send(CAN_ID(MOTOR_NODE[wheel], MC_CMD_SET_STATE), &run, 1);
    motors[wheel].asked_ms = now;
}

static void send_current(int wheel, float amps)
{
    uint8_t data[4];
    can_put_f32(data, amps);
    hal_can_send(CAN_ID(MOTOR_NODE[wheel], MC_CMD_SET_IQ), data, 4);
}

static int is_running(const Motor *m)
{
    return m->state == MC_STATE_RUN && m->mode == MC_MODE_TORQUE;
}

void motors_command(const float torque_nm[4], int enable, uint32_t now)
{
    int just_disabled = was_enabled && !enable;
    if (enable && !was_enabled) enabled_ms = now;
    was_enabled = enable;

    // no torque until all four run, or the running side alone would yaw the car
    int all_running = 1;
    for (int wheel = 0; wheel < 4; wheel++)
        all_running &= is_running(&motors[wheel]);

    for (int wheel = 0; wheel < 4; wheel++) {
        Motor *m    = &motors[wheel];
        int may_ask = now - m->asked_ms >= MOTOR_RETRY_MS;

        if (!enable) {
            send_current(wheel, 0.0f); // in case the idle request is lost
            if (just_disabled || (m->state == MC_STATE_RUN && may_ask)) {
                send_state(wheel, MC_RUN_IDLE, now);
            }
            continue;
        }
        if (!is_running(m) && may_ask) send_state(wheel, MC_RUN_TORQUE, now);
        float amps = torque_nm[wheel] * MOTOR_DIRECTION[wheel] / MOTOR_NM_PER_AMP;
        send_current(wheel, all_running ? amps : 0.0f);
    }
}

int motors_refusing(uint32_t now)
{
    if (!was_enabled || now - enabled_ms < MOTOR_START_MS) return 0;
    for (int wheel = 0; wheel < 4; wheel++) {
        if (!is_running(&motors[wheel])) return 1;
    }
    return 0;
}

void motors_clear_faults(void)
{
    for (int wheel = 0; wheel < 4; wheel++) {
        hal_can_send(CAN_ID(MOTOR_NODE[wheel], MC_CMD_CLEAR_FAULTS), NULL, 0);
    }
}

void motors_estop(void)
{
    hal_can_send(CAN_ESTOP_ID, NULL, 0);
}

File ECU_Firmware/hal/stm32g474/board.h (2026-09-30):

/* Pin map of the ECU board (U11, STM32G474CEU6), taken from ECU_Hardware/schematics.
   PC4 (IMU_INT) and PA8 (GPS_PPS) are wired but not used yet. */
#ifndef BOARD_H
#define BOARD_H

#include "stm32g4xx.h"

/* ---- pin map ----

   PA0 TEMP_SENSE ADC1_IN1    PA4 IMU_CS_N GPIO       PA9  GPS_TX    USART1 AF7
   PA1 APPS_1     ADC1_IN2    PA5 IMU_SCK  SPI1 AF5   PA10 GPS_RX    USART1 AF7
   PA2 APPS_2     ADC1_IN3    PA6 IMU_MISO SPI1 AF5   PB4  CAN_FAULT input
   PA3 BPPS       ADC1_IN4    PA7 IMU_MOSI SPI1 AF5   PB5  CAN_RX    FDCAN2 AF9
   PB0 STEERING   ADC1_IN15   PB9 HEARTBEAT LED       PB6  CAN_TX    FDCAN2 AF9
   PB1 VIN_SENSE  ADC1_IN12   PA11/PA12 USB */

#define LED_PIN       9 // PB9
#define IMU_CS_PIN    4 // PA4
#define CAN_FAULT_PIN 4 // PB4, TCAN337G FAULT goes high on a transceiver fault

enum { PIN_IN, PIN_OUT, PIN_AF, PIN_ANALOG };

static inline void pin_mode(GPIO_TypeDef *port, uint32_t pin, uint32_t mode, uint32_t af)
{
    port->MODER = (port->MODER & ~(3u << (pin * 2))) | (mode << (pin * 2));
    if (mode == PIN_AF) {
        port->OSPEEDR |= 3u << (pin * 2);
        uint32_t shift      = (pin & 7) * 4;
        port->AFR[pin >> 3] = (port->AFR[pin >> 3] & ~(0xFu << shift)) | (af << shift);
    }
}

void board_init(void);

#endif

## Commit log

2026-09-14 Added ecu_hardware schematics
    [Ambient_Temperature.kicad_sch, CAN.kicad_sch, Connectors.kicad_sch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]
2026-09-14 Change project name to STM32 Torque Vectoring ECU
    Updated project title and description in README.
2026-09-30 Replace the HIL simulation with the STM32 ECU firmware
    The repo now holds the firmware for the torque vectoring and derating ECU
    (STM32G474CEU6) that commands four STM32 motor controllers over CAN. The
    full-physics simulation that used to live here stays in git history; HIL
    testing moves to the Formula Student simulator, which talks to this ECU
    over CAN.
    - app/: portable application. Proportional yaw-rate torque vectoring,
    derating (FET and board temperature, motor speed, bus voltage, regen
    fade near standstill), pedals and steering with FS plausibility rules,
    startup/standby/drive states, motor controller CAN client, HIL inputs,
    LSM6DSV16X and NMEA drivers, USB console
    - hal/stm32g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
    [adc.c, app.c, app.h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]
2026-09-30 Move ECU schematics into schematics/ and add driver inputs and sensor notes
    Hierarchical sheets now live in ECU_Hardware/schematics, with the new
    Driver_Inputs sheet (APPS, BPPS and steering dividers and clamps), the
    reviewed and JLCPCB project symbol libraries, new 3D models, and
    SENSOR_INTERFACES.md with the GPS, IMU and temperature pin allocation.
    The old top-level sheets and the restore backup are removed.
    Claude-Session: https://claude.ai/code/session_0117trEbCv7z6CPYkN3K3GKQ
    [Ambient_Temperature.kicad_sch, CAN.kicad_sch, Connectors.kicad_sch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]
2026-10-02 Add a latched FAULT state and steering wheel panel dials
    A hard stop while driving now latches ECU_FAULT instead of dropping to standby. The cause stays in the status frame until the console clear command or a power cycle.
    A steering wheel panel (CAN node 17) sends torque vectoring, drive power and regen dials. They scale the yaw correction and the torque limits, and the last values are held if the panel goes quiet.
    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
    [app.c, app.h, can_protocol.h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]
2026-10-05 Run the planner, pure pursuit and speed control on the ECU
    With HIL_FLAG_AUTONOMY the ECU reads cone frames, builds a centre line, steers
    and sets the total torque request, and sends them back in ECU_MSG_COMMAND.
    Stale cones latch FAULT. Adds planner and autonomy tests and ECU tests for the
    cone frames.
    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
